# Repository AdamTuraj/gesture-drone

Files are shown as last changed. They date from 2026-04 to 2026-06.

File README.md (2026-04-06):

# Gesture Controlled Drone

Drone Frame

## Overview

This is my custom gesture-controlled micro drone project. The repo includes the frame and mechanical design, the ESP32-CAM board work, and software used for video streaming/control.

Still very much a work-in-progress on the software side.

## What's in this repo

- [CAD](CAD/) - Drone frame, mounts, props, and assembly files
- [PCB](PCB/) - Custom camera/ESP32 board design files, outputs, and BOM
- [Code](Code/) - Firmware and software for the drone and RPI

## Current Status

- Airframe and PCB design are done
- Firmware/software is in progress
- Iterating on full gesture control workflow

## License

- Hardware (CAD + PCB): CERN-OHL-W v2 - see [LICENSE-HARDWARE](LICENSE-HARDWARE)
- Software (Code): MIT - see [LICENSE](LICENSE)

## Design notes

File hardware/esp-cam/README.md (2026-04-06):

# Barebones ESP32-CAM

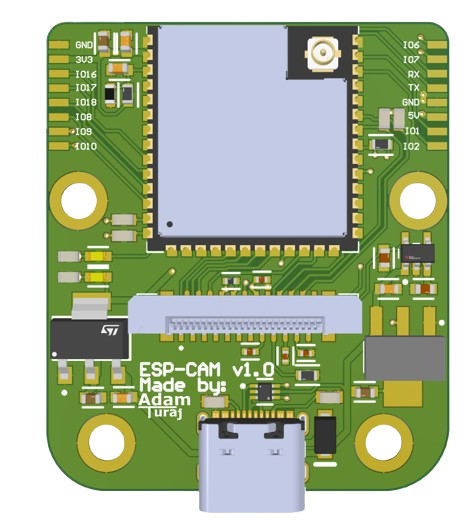
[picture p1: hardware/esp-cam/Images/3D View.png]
A Top 3d view of the board


## Overview

When building a drone, space and weight are critical considerations. Most commercial ESP32-CAM modules feature a double-stacked design that complicates packaging and includes unnecessary features for aerial applications. This custom-designed board addresses these limitations with a compact, flat, single-stack PCB optimized for drone integration.

## Features

- **ESP32-WROOM-1U Module**
  - Native 8-bit camera interface
  - External antenna for extended range
  - Built-in USB flashing (eliminates USB-to-UART converter requirement)
- **40-Pin FPC Connector** for OV2640 camera module
  - Integrated 5V to 2.8V and 5V to 1.8V LDO regulators for camera power
- **USB-C Port** for programming and debugging
- **GPIO Expansion** - All GPIO pins exposed via headers
- **Flexible Power Options**
  - USB-powered or external 5V supply
  - Reverse current protection via Schottky diode

## Assembly

This board can be manufactured through JLCPCB with their PCB Assembly (PCBA) service. The bill of materials is provided below, and the complete PCBA BOM is available at [Output/JLC_BOM.xlsx](Output/JLC_BOM.xlsx).

**Note:** The ESP32-WROOM-1U module must be purchased and soldered separately, as it cannot be included in the standard JLCPCB PCBA service.

### Bill of Materials

| Item | Cost | Quantity | Link |
| --- | --- | --- | --- |
| PCB from JLC | $45.51 | 1 | [Images/Cart.png](Images/Cart.png) |
| ESP32-WROOM-1U | $5.33 | 1 | https://www.lcsc.com/product-detail/C3013946.html |
| OV2640 Camera  | $6.65 | 1 | https://www.aliexpress.com/item/1005003040149873.html |
| **Total** | **$57.49** | | |

## Board Images

### Schematic

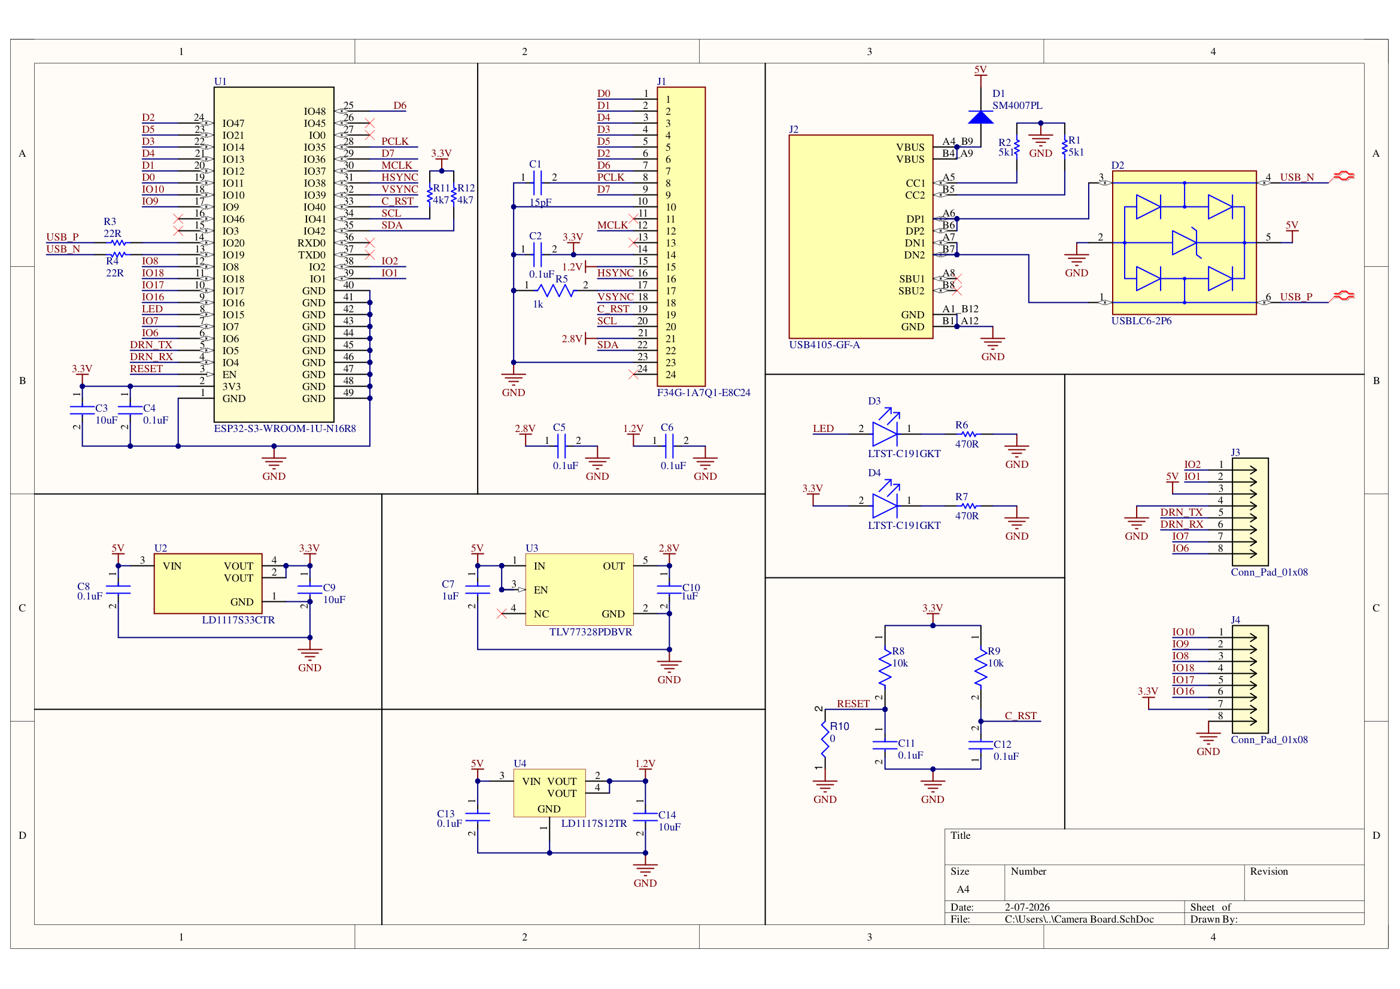
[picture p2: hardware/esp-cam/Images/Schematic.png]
Schematic


### Top Layer (Signal / GND)

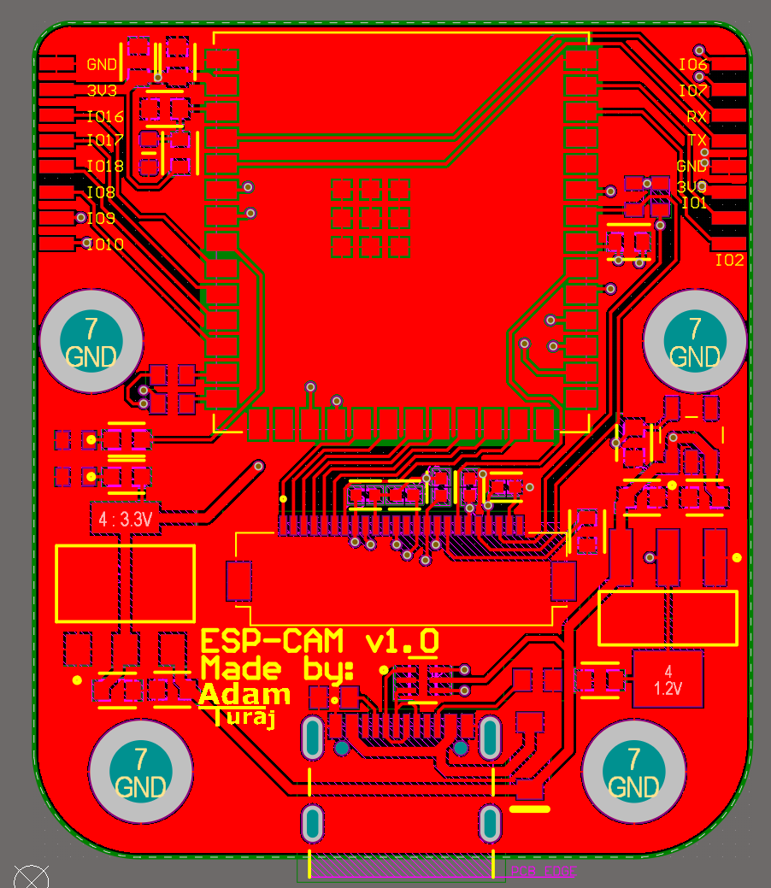
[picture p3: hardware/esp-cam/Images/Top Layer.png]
Top PCB Layer


### Bottom Layer (Signal / GND)

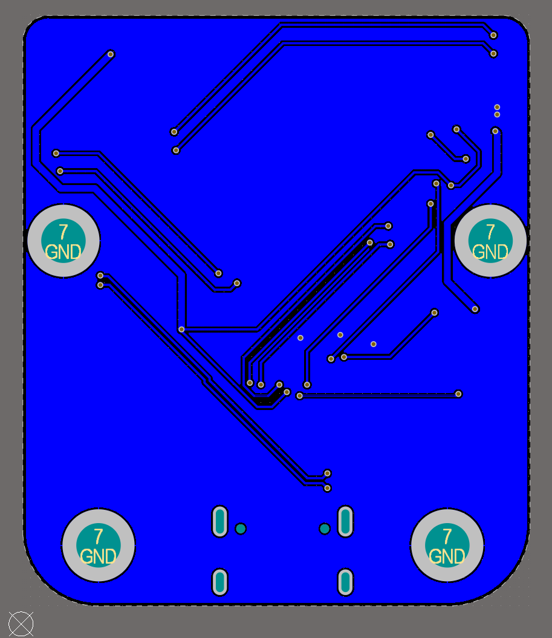
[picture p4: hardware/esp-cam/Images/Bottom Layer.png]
Bottom PCB Layer


## License

This ESP32-CAM hardware is licensed under CERN-OHL-S v2. See the full license text in [../LICENSE-HARDWARE](../LICENSE-HARDWARE).

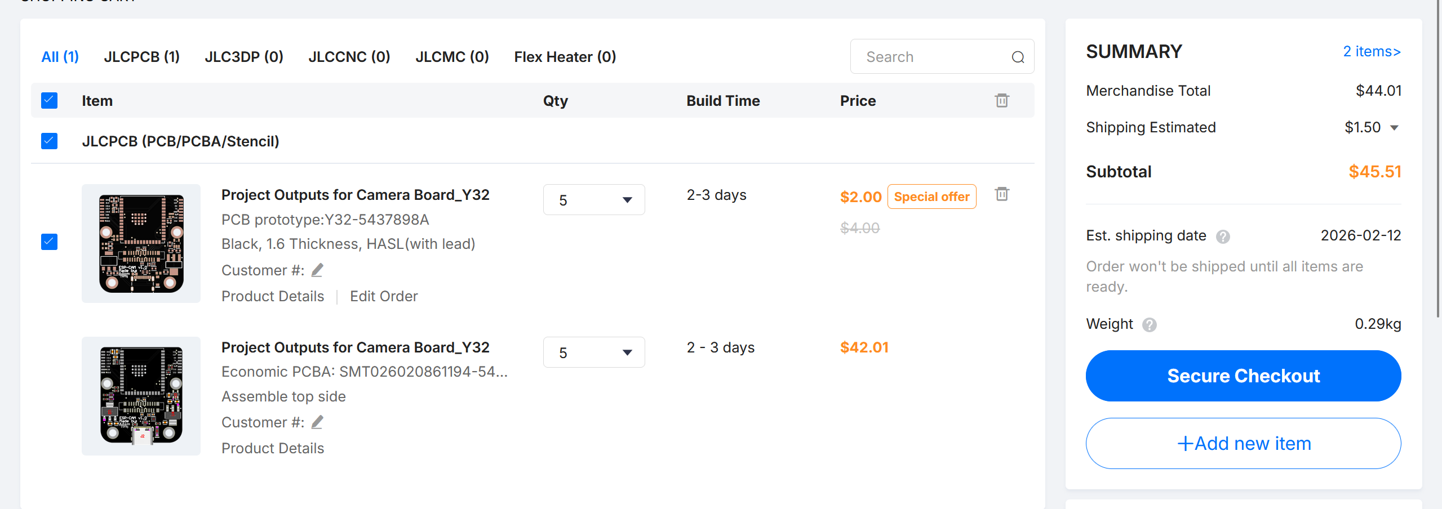
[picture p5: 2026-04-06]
hardware/esp-cam/Images/Cart.png

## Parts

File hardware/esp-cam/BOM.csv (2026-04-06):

Item | Cost | Quantity | Link
PCB from JLC | $45.51 | 1 | https://github.com/AdamTuraj/ESP-CAM/Images/Cart.png
ESP32-WROOM-1U | $5.33 | 1 | https://www.lcsc.com/product-detail/C3013946.html
OV2640 Camera | $6.65 | 1 | https://www.aliexpress.com/item/1005003040149873.html
Subtotal | $57.49
Tax (13%) | $7.47
Total | $64.96

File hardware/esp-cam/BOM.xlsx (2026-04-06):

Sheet: BOM
Item | Cost | Quantity | Link
PCB from JLC | $45.51 | 1 | https://github.com/AdamTuraj/ESP-CAM/Images/Cart.png
ESP32-WROOM-1U | $5.33 | 1 | https://www.lcsc.com/product-detail/C3013946.html
OV2640 Camera | $6.65 | 1 | https://www.aliexpress.com/item/1005003040149873.html
Subtotal | $57.49
Tax (13%) | $7.47
Total | $64.96

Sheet: LCSC Components
Comment | Description | Designator | Footprint | LibRef | Quantity | JLCNUM
15pF | CAP CER 15PF 50V C0G/NPO 0402 | C1 | FP-CC0402-0_55-IPC_B | CMP-03422-001519-1 | 1 | C1548
0.1uF | Chip Multilayer Ceramic Capacitors for General Purpose, 0402, 0.10uF, X7R, 15%, 10%, 50V | C2, C5, C6, C12 | FP-GRM155-0_05-IPC_B | CMP-2008-04639-2 | 4 | C307331
10uF | CAP CER 10UF 10V X5R 0603 | C3, C9, C14 | FP-GRM18-0_15-MFG | CMP-2000-05448-2 | 3 | C19702
0.1uF | CAP CER 0.1UF 50V X7R 0603 | C4, C8, C11, C13 | FP-CC0603-DA-MFG | CMP-2100-03601-2 | 4 | C14663
1uF | CAP CER 1UF 50V X7R 0603 | C7, C10 | FP-CC0603-DB-MFG | CMP-03422-000761-2 | 2 | C15849
SM4007PL | Silion Rectifier, 1 A, 1000 V, -65 to 175 degC, 2-Pin SMD, RoHS, Tape and Reel | D1 | MCC-SOD-123FL_V | CMP-2000-07084-1 | 1 | C64898
USBLC6-2P6 | TVS DIODE 5.25V 17V SOT666 | D2 | FP-SOT-666-MFG | CMP-12225-000058-1 | 1 | C15999
LTST-C191GKT | LED GREEN CLEAR CHIP SMD | D3, D4 | FP-LTST-C191GKT-MFG | CMP-22017-000029-1 | 2 | C99289
F31W-1A7H1-11024 | Flex Connector, 0.50mm Pitch, Height 4.25mm, Vertical, Slider type, ZIF, 24 position, Without MYLAR | J1 | AMPHENOL_F31W-1A7H1-11024 | CMP-002-00071-1 | 1 | C5406215
USB4105-GF-A |  | J2 | GCT_USB4105-GF-A | CMP-003-000000-3 | 1 | C2765186
Conn_Pad_01x08 | Description | J3, J4 | CONN_SM08B-GHS-TB_JST | CMP-005-000000-2 | 2
5k1 |  | R1, R2 | RESC1608X55X25ML10T15 | CMP-2000-04091-1 | 2 | C23186
22R | Chip Resistor, 22 Ohm, +/- 1%, 0.1 W, -55 to 155 degC, 0603 (1608 Metric), RoHS, Tape and Reel | R3, R4 | RESC1608X55X25NL10T15 | CMP-1659-00033-1 | 2 | C23345
1k | RES 1K OHM 1% 1/10W 0603 | R5 | FP-RC0603-0_55-IPC_C | CMP-1659-00009-5 | 1 | C21190
470R | General Purpose Chip Resistor, 470 Ohm, +/- 1%, -55 to 155 degC, 0603 (1608 Metric), RoHS, Tape and Reel | R6, R7 | RESC1608X55X25LL10T15 | CMP-1659-00035-2 | 2 | C23179
10k | RES 10K OHM 1% 1/10W 0603 | R8, R9 | FP-RC0603-0_55-IPC_C | CMP-2100-03664-2 | 2 | C25804
Jumper 0603 | Jumper 0603 | R10 | RESC0603(1608)_L | CMP-009-00175-3 | 1
4k7 | Chip Resistor, 4.7 KOhm, +/- 1%, 0.1 W, -55 to 155 degC, 0603 (1608 Metric), RoHS, Tape and Reel | R11, R12 | RESC1608X55X25LL10T15 | CMP-2000-06942-1 | 2 | C23162
ESP32-S3-WROOM-1U-N16R8 | Description | U1 | ESP32-S3-WROOM-1U_EXP | CMP-288-000000-2 | 1 | C3013946
LD1117S33CTR | IC REG LINEAR 3.3V 800MA SOT223 | U2 | FP-SOT-223-0046067_14-MFG | CMP-0244-00307-2 | 1 | C35879
TLV77328PDBVR | 300-mA high-PSRR low-IQ low-dropout regulator with enable 5-SOT-23 -40 to 85 | U3 | DBV0005A_MFG | CMP-00370-149257704-1 | 1 | C31261045
LD1117S12TR | Fixed Low Drop Positive Voltage Regulator, 1.2V, 4-Pin SOT-223, Tape and Reel | U4 | SOT-223_M | CMP-0244-00318-1 | 1 | C155612

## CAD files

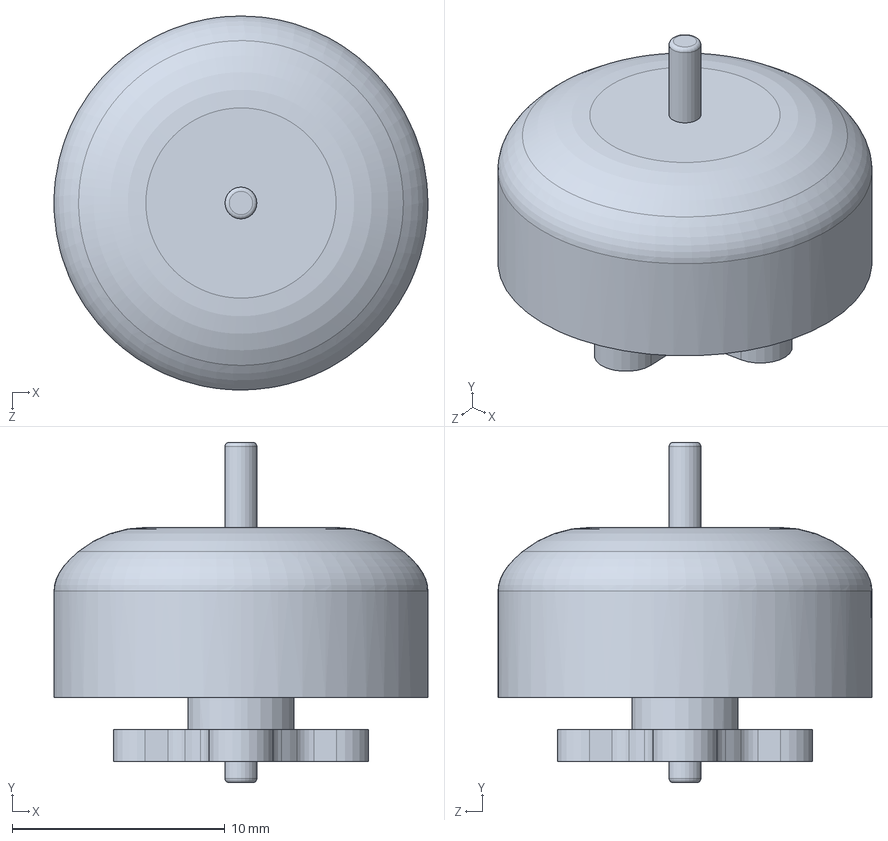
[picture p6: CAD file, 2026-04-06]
hardware/drone_frame/Xing 1303.SLDPRT
17.6 x 16.0 x 17.6 mm

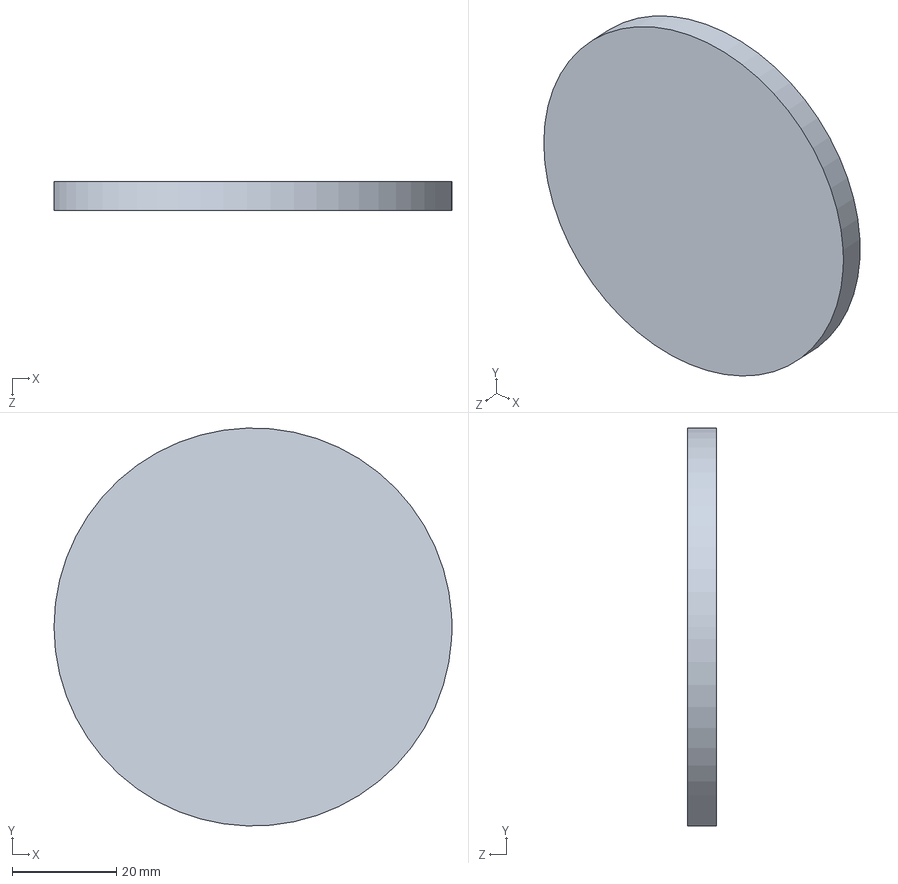
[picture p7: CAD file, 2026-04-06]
hardware/drone_frame/Prop.SLDPRT
76.5 x 76.5 x 5.50 mm

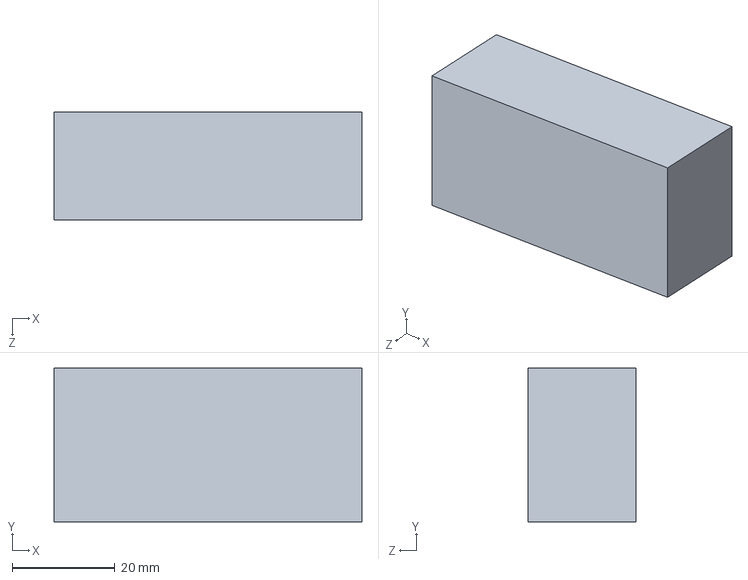
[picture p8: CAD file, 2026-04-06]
hardware/drone_frame/Battery.SLDPRT
60.0 x 30.0 x 21.0 mm

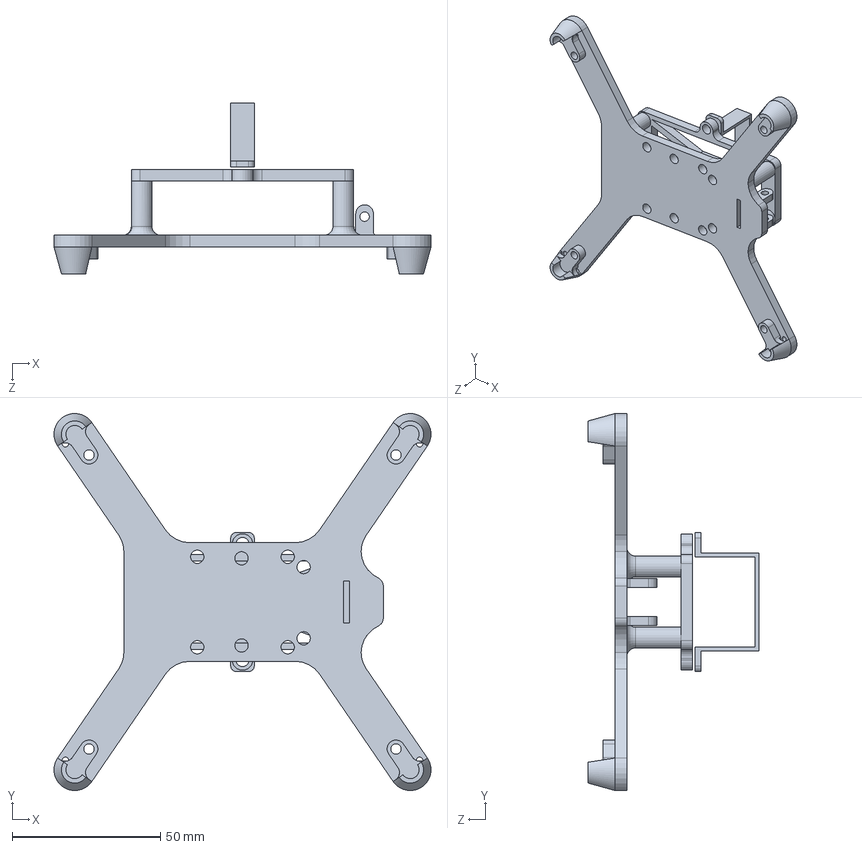
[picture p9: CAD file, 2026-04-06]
hardware/drone_frame/Frame.SLDPRT
127.1 x 127.1 x 57.5 mm

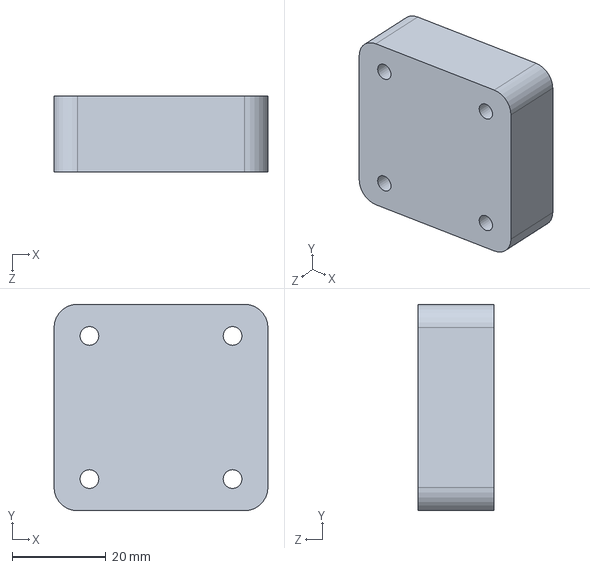
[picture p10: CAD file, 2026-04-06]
hardware/drone_frame/SpeedyBee.SLDPRT
45.6 x 44.0 x 16.1 mm

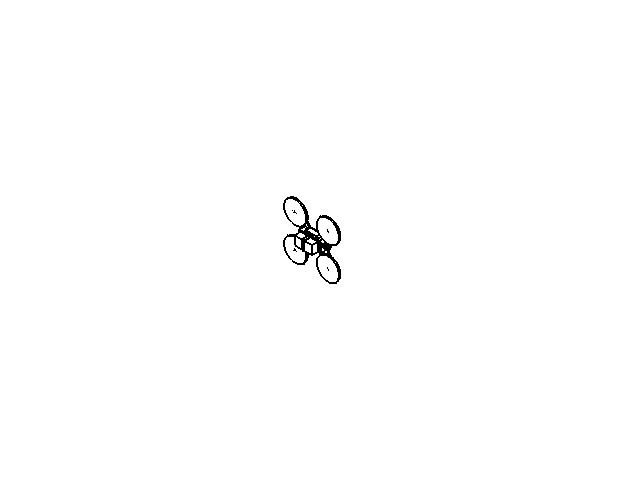
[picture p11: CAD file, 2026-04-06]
hardware/drone_frame/Drone.SLDASM
SpeedyBee
Battery
Frame
Camera Mount
Copy of Body_2^objective_camera_OV2640
Copy of Lense^objective_camera_OV2640
box^camera_OV2640
plate^camera_OV2640
Copy of Open CASCADE STEP translator 7.5 1.1.1^Board_Camera Board
Copy of F314_336_31W_31Z_L.STEP^Copy of F31W-1A7H1-11024.STEP_Copy of 8409083552_J1_Camera Board
Copy of F314_336_31W_31Z_M.STEP^Copy of F31W-1A7H1-11024.STEP_Copy of 8409083552_J1_Camera Board x 10
Copy of F314_336_31W_31Z_R_EVEN.STEP^Copy of F31W-1A7H1-11024.STEP_Copy of 8409083552_J1_Camera Board
Copy of Extruded-4^Copy of 8878084128_U4_Camera Board
Copy of BODY-SOT^Copy of SOT95P280X118-5_DBV0005A_U3_Camera Board
Copy of LEAD-SOT^Copy of SOT95P280X118-5_DBV0005A_U3_Camera Board x 5
Copy of Texas Logo Yury^Copy of SOT95P280X118-5_DBV0005A_U3_Camera Board
Copy of Texas Logo Yury - Copy^Copy of SOT95P280X118-5_DBV0005A_U3_Camera Board
Copy of body-5^Copy of IC_STMicroelectronics_LDL1117S50R_eec_U2_Camera Board
Copy of terminals-6^Copy of IC_STMicroelectronics_LDL1117S50R_eec_U2_Camera Board
Copy of logo-7^Copy of IC_STMicroelectronics_LDL1117S50R_eec_U2_Camera Board
Copy of ESP32-S3-WROOM-1U-N16R8^U1_Camera Board
Copy of USB4105GFA_USB4105GFA^Copy of USB4105-GF-A_J2_Camera Board
Xing 1303 x 4
Prop x 4

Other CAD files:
hardware/drone_frame/camera_OV2640.SLDASM
hardware/drone_frame/Camera Board.SLDASM
hardware/drone_frame/Camera Mount.SLDPRT

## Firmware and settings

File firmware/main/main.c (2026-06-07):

#include <stdio.h>
#include <string.h>

#include "esp_err.h"
#include "esp_log.h"
#include "esp_random.h"
#include "freertos/FreeRTOS.h"
#include "freertos/task.h"

#include "mavlink_bridge.h"
#include "camera.h"
#include "usb_video.h"

void app_main(void)
{
    ESP_LOGI("Main", "Starting USB video + MAVLink heartbeat test...");

    // Initialize MAVLink communication
    mavlink_bridge_init();
    mavlink_bridge_init_queues();

    ESP_LOGI("Main", "WiFi features disabled for this test build");
    esp_err_t usb_video_err = usb_video_init();
    esp_err_t camera_err = camera_init();

    // Create a task to receive MAVLink messages
    xTaskCreate(mavlink_bridge_rx_task, "ReceiveMavlinkTask", 4096, NULL, 5, NULL);
    xTaskCreate(mavlink_bridge_heartbeat_probe_task, "HeartbeatProbeTask", 4096, NULL, 5, NULL);

    if (camera_err == ESP_OK)
    {
        xTaskCreate(camera_capture_task, "CameraCaptureTask", 4096, NULL, 4, NULL);

        if (usb_video_err == ESP_OK)
        {
            xTaskCreate(usb_video_stream_task, "UsbVideoTask", 4096, NULL, 4, NULL);
        }
        else
        {
            ESP_LOGW("Main", "USB video disabled because init failed: %d", usb_video_err);
        }
    }
    else
    {
        ESP_LOGW("Main", "Camera disabled because init failed: %d", camera_err);
    }
}

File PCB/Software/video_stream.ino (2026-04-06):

// Video streaming example using ESP32-CAM. Code taken from https://docs.cirkitdesigner.com/component/b03da137-6105-4f5a-a6f4-6983b68cc78f/esp-cam-ov2640

#include <WiFi.h>
#include <esp_camera.h>

// Replace with your Wi-Fi credentials
const char *ssid = "Your_SSID";
const char *password = "Your_PASSWORD";

// Camera configuration
#define PWDN_GPIO_NUM -1
#define RESET_GPIO_NUM 40
#define XCLK_GPIO_NUM 37
#define SIOD_GPIO_NUM 42
#define SIOC_GPIO_NUM 41
#define Y9_GPIO_NUM 36
#define Y8_GPIO_NUM 48
#define Y7_GPIO_NUM 21
#define Y6_GPIO_NUM 13
#define Y5_GPIO_NUM 14
#define Y4_GPIO_NUM 47
#define Y3_GPIO_NUM 12
#define Y2_GPIO_NUM 11
#define VSYNC_GPIO_NUM 39
#define HREF_GPIO_NUM 38
#define PCLK_GPIO_NUM 35

void setup()
{
    Serial.begin(115200);

    // Connect to Wi-Fi
    WiFi.begin(ssid, password);
    while (WiFi.status() != WL_CONNECTED)
    {
        delay(500);
        Serial.print(".");
    }
    Serial.println("\nWi-Fi connected");

    // Initialize the camera
    camera_config_t config;
    config.ledc_channel = LEDC_CHANNEL_0;
    config.ledc_timer = LEDC_TIMER_0;
    config.pin_d0 = Y2_GPIO_NUM;
    config.pin_d1 = Y3_GPIO_NUM;
    config.pin_d2 = Y4_GPIO_NUM;
    config.pin_d3 = Y5_GPIO_NUM;
    config.pin_d4 = Y6_GPIO_NUM;
    config.pin_d5 = Y7_GPIO_NUM;
    config.pin_d6 = Y8_GPIO_NUM;
    config.pin_d7 = Y9_GPIO_NUM;
    config.pin_xclk = XCLK_GPIO_NUM;
    config.pin_pclk = PCLK_GPIO_NUM;
    config.pin_vsync = VSYNC_GPIO_NUM;
    config.pin_href = HREF_GPIO_NUM;
    config.pin_sscb_sda = SIOD_GPIO_NUM;
    config.pin_sscb_scl = SIOC_GPIO_NUM;
    config.pin_pwdn = PWDN_GPIO_NUM;
    config.pin_reset = RESET_GPIO_NUM;
    config.xclk_freq_hz = 20000000;
    config.pixel_format = PIXFORMAT_JPEG;

    if (esp_camera_init(&config) != ESP_OK)
    {
        Serial.println("Camera initialization failed");
        return;
    }
    Serial.println("Camera initialized successfully");
}

void loop()
{
    // Capture an image
    camera_fb_t *fb = esp_camera_fb_get();
    if (!fb)
    {
        Serial.println("Failed to capture image");
        return;
    }

    // Print image size
    Serial.printf("Captured image size: %d bytes\n", fb->len);

    // Return the frame buffer to the driver
    esp_camera_fb_return(fb);

    delay(5000); // Wait 5 seconds before capturing the next image
}

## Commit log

2026-05-14 Update PCB
    [Camera Board.GBL, Camera Board.GBO, Camera Board.GBP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]
2026-05-16 Rewrite firmware to use Mavlink; Add camera and UDP server
2026-06-07 Update camera to properly work, add USB video for testing (USB test vibecoded)
2026-06-08 Update file structure and change CV code to ROS
    [BOM.csv, BOM.xlsx, Battery.SLDPRT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]
